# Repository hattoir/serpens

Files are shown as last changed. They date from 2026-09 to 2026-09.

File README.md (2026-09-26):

# Serpens EX-1 — 展示用ヘビ型ロボット 制御ソフトウェア

9軸（胴体ヨー×6 + 首ピッチ J7 + 頭ヨー J8 + 頭ロール J9）のヘビ型ロボットを、Python だけで動かすための
ソフトウェアです。**モックファースト**で作っており、実機が1台もなくてもシミュレータ上で全機能が動きます。

- ROS 2 不使用 / LLM 不使用（行動選択は手書きの効用関数）
- 寸法・しきい値・ゲインは全部 `config/robot.yaml`（コードにマジックナンバーを書かない）
- 実機接続は `--bus feetech --port COM5`。**ただし引数を足すだけで展示ができるわけではない**。
  実機は待機（停止）から始まり、**実観測の自己位置・床の校正・ESP32 駆動リンク**が揃うまで
  自律走行は開始できない（`serpens/safety.py`）。ESP32 ファームは Phase 2 で作る（未実装）

---

## 1. セットアップ（Windows 11 / Python 3.12）

PowerShell で、このフォルダ（`serpens/`）に移動してから実行します。

```powershell
py -3.12 -m venv .venv
.\.venv\Scripts\python.exe -m pip install --upgrade pip
.\.venv\Scripts\python.exe -m pip install -r requirements.txt
.\.venv\Scripts\python.exe -m pip install --no-deps -r requirements-nodeps.txt
.\.venv\Scripts\python.exe tools\check_env.py
.\.venv\Scripts\python.exe -m pytest
```

`Activate.ps1` で venv を有効化したい場合、PowerShell の実行ポリシーで止められることがあります。
その場合は上のように `.\.venv\Scripts\python.exe` を直接呼べば有効化は不要です。
VSCode ではコマンドパレット →「Python: Select Interpreter」→ `.venv` を選んでください。

### なぜ2段階インストールなのか（opencv の競合）

ArUco を使うので **`opencv-contrib-python` だけ**を入れます。ところが `ultralytics` は
`opencv-python` に依存しており、普通に `pip install ultralytics` すると両方が入って `cv2` が壊れます
（`cv2.aruco` が消える、import が不定になる等）。

そこで:
1. `requirements.txt` … ultralytics の依存を **opencv-python だけ除いて** 列挙
2. `requirements-nodeps.txt` … ultralytics 本体を `--no-deps` で入れる

`pip check` は「ultralytics requires opencv-python」と警告しますが、**想定どおりなので無視**してください。
万一 `opencv-python` が入ってしまったら:

```powershell
.\.venv\Scripts\python.exe -m pip uninstall -y opencv-python opencv-python-headless opencv-contrib-python
.\.venv\Scripts\python.exe -m pip install opencv-contrib-python
```

### サーボ SDK について

`ftservo-python-sdk`（Feetech 公式リポジトリ由来、import 名 `scservo_sdk`）を使います。
`WritePosEx()`（位置・速度・加速度の同時指定）、`read1ByteTxRx()` / `read2ByteTxRx()`、
Sync Read / Sync Write が揃っています。
よく似た名前の `feetech-servo-sdk` は機能削減版（`sms_sts` が無い）で、しかも同じ `scservo_sdk` という
名前でインストールされて上書きし合うので、**入れないでください**（`tools/check_env.py` が検出します）。
なお `scservo-sdk` という名前のパッケージは PyPI にありません。

### YOLO の重み（人物検出に必要。自動ダウンロードはしない）

**展示会場にネットは無い前提**です。ultralytics は重みのダウンロードや更新確認で勝手に外へ出るので、
`serpens/app.py` の先頭で次を設定してから import しています（import より前でないと効きません）。

```
YOLO_AUTOINSTALL=false   足りないパッケージを勝手に pip install しない
YOLO_OFFLINE=true        オンライン判定を常に false にする（重みの取得・更新確認をしない）
YOLO_HUB_OFFLINE=true    Ultralytics HUB へ通信しない
```

**置いてある重み**（取得済み。git には入れない）

| 項目 | 値 |
|---|---|
| ファイル | `models/yolo11n.pt`（場所は config の `person.model_path`） |
| 取得元 | https://github.com/ultralytics/assets/releases/download/v8.3.0/yolo11n.pt |
| サイズ | 5,613,764 バイト |
| SHA256 | `0ebbc80d4a7680d14987a577cd21342b65ecfd94632bd9a8da63ae6417644ee1` |
| 取得日 | 2026-09-12 |

置き直すときは上の URL から取得し、SHA256 が一致することを確認してください。

```powershell
.\.venv\Scripts\python.exe -c "import hashlib,pathlib;print(hashlib.sha256(pathlib.Path('models/yolo11n.pt').read_bytes()).hexdigest())"
```

**動作確認**（ultralytics 同梱の bus.jpg。4人写っています）

```powershell
.\.venv\Scripts\python.exe tools\perception_live.py --source .venv\Lib\site-packages\ultralytics\assets\bus.jpg --homography output\_test_h.json --frames 1 --no-window
# → [  0.00s] markers=[]  人=4
```

**オフライン起動の確認（展示前に必ず実行）**

ネットワークを遮断した状態で最後まで動くことを、次のツールで確認できます（外へ出ようとした瞬間にエラーになります）。

```powershell
.\.venv\Scripts\python.exe tools\offline_check.py --camera 0 --gui --seconds 12
# → [オフライン検証] 最後まで動きました
```

`pytest tests/test_offline.py` でも、遮断下で重みの読み込みと推論ができることを確認しています。

**注意**: YOLO の CPU 推論中は Python の GIL を握るため、制御周期が跳ねます（実測: 最悪 96ms、12秒で11回）。
`person.detect_hz`（既定 5Hz）と `person.imgsz`（既定 480）で調整できます。

---

## 2. Windows 固有の注意

### 2.1 COM ポート番号の確認

サーボ用（Waveshare Bus Servo Adapter (A)）と頭部用（XIAO ESP32S3）で **USB が2本**あり、
それぞれ別の COM 番号になります。どちらがどちらか、1本ずつ抜き差しして確認してください。

- **デバイスマネージャ**: スタートボタン右クリック → デバイスマネージャ →「ポート (COM と LPT)」
- **PowerShell**: `[System.IO.Ports.SerialPort]::GetPortNames()`
- **Python（pyserial）**: `.\.venv\Scripts\python.exe -m serial.tools.list_ports -v`

COM 番号は USB の挿し口を変えると変わることがあります。展示会場では**毎回同じ口に挿す**こと。
番号を固定したい場合はデバイスマネージャ → ポートのプロパティ → ポートの設定 → 詳細設定 →
「COM ポート番号」で変更できます。

### 2.2 Waveshare Bus Servo Adapter (A) の接続

- 基板に **USB Type-C** があり、ジャンパ2個で切り替えます:
  **位置A = UART制御 / 位置B = USB制御（PC直結）** → 本プロジェクトは **位置B**。
  別途 USB-TTL 変換器は不要で、これ1枚で PC から直結できます（LeRobot SO-100/SO-101 と同じ標準構成）。
- 半二重（TX/RX 1本線）の方向切替は基板上で処理されるので、**PC側でエコーバックを読み捨てる処理は不要**です。
- USB 側はネイティブの USB CDC と見込んでいます（LeRobot のポート例が `ttyACM0` / `usbmodem` のため）。
  Windows では「USB シリアル デバイス (COMx)」として**標準ドライバで認識され、CH340 等のドライバ導入は不要**の見込み。
  （`ttyACM` は「CDC-ACM クラス」という意味なので、CDC 対応の変換チップの可能性もあります。
  どちらでも Windows 標準ドライバで動く点は同じです。）→ **実機で要確認**

### 2.3 USB シリアルの latency timer（CH340系の USB-TTL を使う場合のみ）

**Bus Servo Adapter (A) はネイティブ CDC なので、この設定は不要の見込みです（実機で要確認）。**
代わりに CH340 / FTDI 系の USB-TTL 変換器でサーボをつなぐ場合だけ、以下を行ってください。

これらのドライバは既定で受信データを最大 16ms 溜めてから PC に渡します。サーボは
「送信 → 応答待ち」を繰り返すので、1往復ごとに最大 16ms 待たされ、9軸 × 50Hz で
キーフレームを送ると**動きがカクつきます**。

手順（FTDI の場合）:
1. デバイスマネージャ →「ポート (COM と LPT)」→ 該当 COM ポートを右クリック →「プロパティ」
2. 「ポートの設定」タブ →「詳細設定」
3. 「待ち時間 (msec)」（英語表示では *Latency Timer (msec)*）を **16 → 1** に変更 → OK
4. **USB を抜き差し**して反映（または PC 再起動）

どの構成でも、実際の往復時間は STEP 8 の `tools/servo_setup.py` で測って確認します。

### 2.4 電源と配線

```
 12V 電源 (5A以上, 推奨10A以上)
    │  DCジャック or ネジ端子
    ▼
 ┌──────────────────────┐  USB-C (ジャンパ=B)
 │ Bus Servo Adapter (A)│──────────────────── PC (COMx)
 └──────────┬───────────┘
            │ 3線 (GND / 12V / 信号) デイジーチェーン
   J1 ─ J2 ─ J3 ─ J4 ─ J5 ─ [★] ─ J6 ─ J7 ─ J8 ─ J9
                              ↑
            必要ならここで 12V を分岐注入（GND 共通）
```

- STS3215 は 1 個あたりロック電流 2.7A（Waveshare Wiki の仕様値）。9 個が同時に踏ん張ると
  電源側は数十 A になり得ます。**律速になるのは電源容量と、デイジーチェーンのコネクタ・細い線の電流容量**です。
- 末端（頭側）で電圧が落ちる場合は、バスの中間で 12V を**分岐注入**してください（GND は必ず共通）。
- 電圧は `read_state()` の電圧で監視できます。展示中の電圧低下はログに残す予定です（STEP 7）。

XIAO ESP32S3（頭部）は別の USB で PC に接続します（115200 bps、行指向 ASCII。仕様は STEP 2 の `head_io.py` 参照）。

### 2.5 その他
- ユーザー名に日本語が含まれていても動作は確認済み（venv / pip / pytest）。
- **`cv2.imread` / `cv2.imwrite` は日本語を含むパスを開けません**（Windows 版 OpenCV の制限）。
  画像の読み書きは `np.fromfile` + `cv2.imdecode` か PIL を使うこと（`perception/camera.py` の ImageSource 参照）。
- COM ポートは同時に1プロセスしか開けません。Arduino IDE や別のシリアルモニタを閉じてから起動すること。

---

## 3. 実行方法（STEP ごとに更新）

### 動作確認用ツール

```powershell
# STEP 2: モックサーボの追従・負荷・温度変化をコンソールに表示
.\.venv\Scripts\python.exe tools\demo_mock_servo.py --heat-tau 60
# STEP 3: 9軸の角度列と、姿勢（home / とぐろ / 鎌首）の形を図にする → output/step3_motion.png
.\.venv\Scripts\python.exe tools\plot_motion.py
# STEP 4: シミュレータを上から見た図（+GIF）と、歩容ごとの「1周期あたりの前進量」
.\.venv\Scripts\python.exe tools\sim_view.py --gif
# STEP 5: 仮想カメラで知覚を試す（本物の ArUco 検出、人は仮想の検出器）→ GIF と時系列グラフ
.\.venv\Scripts\python.exe tools\perception_demo.py
# STEP 5: 実写（印刷したマーカ）。先に四隅をクリックして床の校正
.\.venv\Scripts\python.exe tools\make_aruco.py            # → output/aruco_markers_A4.png を実寸で印刷
.\.venv\Scripts\python.exe tools\calibrate_floor.py --source 0
.\.venv\Scripts\python.exe tools\perception_live.py --source 0
# STEP 6: 人の座標を動かして一連の振る舞いを見る → output/step6_behavior.gif と内部状態の時系列
.\.venv\Scripts\python.exe tools\behavior_demo.py
```

### 行動の設計（STEP 6）

毎制御周期（50Hz）の流れ（`behavior/brain.py`）:

```
知覚（ヘビの位置姿勢・追跡中の1人・タッチ・サーボ最高温度）
 → 刺激（presence / proximity / approach / touch / novelty / looking / alone）
 → 内部状態（Curiosity / Affection / Stress / Attention = 一次遅れ、Energy = サーボ温度から）
 → 効用（9状態、±8% の乱数）→ 状態機械（ヒステリシス 1.15 倍・最小継続 4 秒）
 → 状態ごとの動作（移動 controller.py / しぐさ expression.py）→ アニメーター → サーボ
```

- `internal_state.py` … dx/dt = −(x−x0)/τ + Σ gain×刺激。係数は `behavior.internal`。
  Energy は最高温度 `temp_fresh_c`（=1）〜`temp_tired_c`（=0）の直線。熱い = 疲れている
- `utility.py` … 手書きの効用（式は docstring）。係数は `behavior.utility.weights`。
  GUI の「いま何を考えているか」は `thought_line()`（例: `Curiosity 0.82 > Rest 0.31 → 接近`）
- `fsm.py` … 最小継続時間（状態ごとに上書き可: PETTED 2s / ALERT 2s / COIL_REST 20s / SLEEP 8s）、
  割り込みは PETTED だけ。ALERT は「新しい人に気づいた瞬間」に直接切り替える
- `controller.py` … 目標点 → γ0（向きの誤差 × ゲイン）と周波数（速さ ÷ 1周期の前進量）。
  周期は遅くするときだけ延ばす（速くするために短くしない）。1m 以内 8cm/s（**気づく前でも必ず**）、
  頭先端から 400mm で停止（歩容が止まるまでの惰性ぶん早めに止める）。
  マット端では後退しながら中央へ向き直る。マットの外の人へ近づくときは、人の方を向いて端に着いたら止まる
- `expression.py` … 生き物らしさ a〜j（数値はすべて `behavior.expression`）
- `sim/session.py` … 実機なしで全部をつないだもの（GUI の `--sim` もこれを使う予定）
- 目の色・明るさは状態ごと（`behavior.eyes`）。ESP32 のフェイルセーフ（3 秒）より短い間隔で送り直す

### 知覚の設計（STEP 5）

- `perception/homography.py` … マット四隅4点 → 画像↔床の射影変換（JSON 保存）。胴体上面のマーカ（高さ 50mm）は
  `camera.position_mm` を与えると視差補正する（高さ 1.5m・水平 1m で約 33mm のずれ）。広角レンズの歪みは取れない
- `perception/aruco_locator.py` … DICT_4X4_50 の ID0（尾）/ ID1（首）。小さいマーカ向けに検出パラメータを調整済み
  （`aruco.detector_params`）。2枚の距離が `aruco.max_marker_gap_mm` を超えたら誤検出として尾を捨てる
- `perception/snake_pose.py` … θ_body は1周期の移動平均（`snake_pose.heading_filter`）。一次ローパスは
  定常旋回で ω·τ（約 40°）遅れるため。移動平均の遅れは τ/2
- `perception/person_detector.py` … YOLO（CPU、person のみ）→ bbox 下辺中央を足元として床座標へ。
  追跡は「ヘビの首に最も近い1人」だけ、切替は 2 秒ヒステリシス、0人でも 3 秒保持、マット中心から 1.5m の外は無視
- `sim/virtual_camera.py` … カメラ無しでも知覚を通しで試せる仮想カメラ（マーカは本物の画像を貼って描く）
- **マーカの大きさ**: 40mm は 1280×720 だとマット奥で 11〜20px しかなく、仮想カメラでも検出率 93〜98%。
  1920×1080 なら 100%。**カメラは 1080p で使う**（`camera.width_px`）
- **カメラとマットの間に人が立つと、マーカが隠れる**（仮想カメラで確認）。カメラの置き場所に注意

### シミュレータの設計（STEP 4）

- `sim/world.py` … 車輪のあるリンク（`sim.wheel_links` = 尾端〜J7 の7リンク × 2輪 = 14輪）は横滑りしない、
  という拘束を全リンク分まとめて最小二乗で解き、胴体全体の剛体速度 (vx, vy, ω) を毎ステップ求める。物理エンジンなし。
  - 車輪の進行方向には転がり抵抗の重み `belly.profiles[type][profile].tangential`（推定値 0.02。**要実機校正**）。腹側は Wheel / Snake を切り替えられる
  - J7 より先は車輪なし。頭部が床にあるときは PTFE / フェルトのパッド（`sim.pad_links`、等方の軽い摩擦）
  - 床から浮いたリンク（鎌首の頭側）は拘束に入れない。マットからはみ出したら全体を内側へ押し戻す
- ヘビの位置姿勢（`perception/snake_pose.py`。ArUco でもシミュレータでも同じ処理）
  - 位置 = 首マーカ。**首マーカは J7 より胴体側（J6-J7 リンク上）に貼る**（J7 より先だと鎌首で傾いて見えない）。
    尾マーカは尾端-J1 リンク上。どちらも上面
  - θ_body = 尾マーカ → 首マーカ。蛇行で振れるので、時定数 = 歩容1周期のローパス後の値を移動制御に使う（生値も保持）
  - θ_head = θ_body + J8（「人を見ているか」の判定用）
- **1周期あたりの前進量（シミュレータ, 転がり抵抗 0.02）**: forward 約 384mm。
  実機では 200〜300mm/周期（周期2秒で 10〜15cm/s）と予想。**速度のために周期を短くしない**（静粛性優先）。
- 旋回は γ（オフセット）だけ。`gait.turn_profile: head_weighted`（γ(n) = γ0·n/N）が既定で、
  γ0 = ±20° で半径 約480mm。γ0 は1周期かけてランプする。
  - uniform と head_weighted を同じ旋回率で比べると半径は同じで、尾が頭の軌跡をなぞる精度が head_weighted の方が上
    （ずれ平均 91mm vs 115mm）。
- とぐろは**尾から順に巻き、頭を最後に引き込む**（`poses.coil_sequence`）。全関節同時より滑走が少ない。

### モーション層の設計（STEP 3）

- 関節角の符号: yaw + = 上から見て左、pitch + = 頭が上がる、roll + = 右に傾く（`motion/kinematics.py`）
- `motion/gait.py` … α(n,t) = A·sin(Ω·n + ω·t) + γ(n)。n=0 が J1（尾側）。ω>0 で前進、ω<0 で後退。
  旋回入力は γ だけ（振幅勾配は平面の蛇行では旋回しないことを確認して削除）。
- `motion/poses.py` … home（J7 = +8°：頭をわずかに浮かせる）/ rest（緩い弧）/ rear_up（土台 arc）/
  stretch（伸び。人がいないときだけ）/ head_look / relax。旧 coil・s_curve は `legacy_poses`。
  head_look で J7 を指定すると「人を見る」範囲（`neck.look_min_deg`〜`look_max_deg`）に制限される。
- `motion/animator.py` … 出力 = キーフレーム + 歩容（加算）+ 呼吸（加算）。
  キーフレームがその軸の `max_speed_dps`（胴体 240 / J7 120 / J8・J9 90 °/s）を超える速さを要求したら、
  自動で時間を延ばす。`order` と `stagger_s` で関節ごとに時間差をつけられる（とぐろを尾から順に）。
  `freeze()` で呼吸も含めて全停止し、`unfreeze()` で続きから再開する。

### ハードウェア層の設計（STEP 2）

- `serpens/hw/servo_bus.py` … 抽象クラス `ServoBus`。角度は**関節角 [deg]**（0° = まっすぐ）。
  ソフトリミット（config の `min_deg` / `max_deg`）でのクランプはここで共通に行う。
  可動域は3段（`geometry_*` ⊇ `mechanical_*` ⊇ `min_deg`/`max_deg`）で、包含関係を `load_config` が検査する。
  胴体ヨーは CAD `Serpens_BELLY_R03_TWO_LINK_REVIEW` の ±64°（干渉なし）に対し operational ±60°（暫定）。
- `serpens/hw/mock_bus.py` … 一次遅れ追従。温度は一次系で、時定数 `mock_servo.heat_tau_s` を変えられる。
- `serpens/hw/feetech_bus.py` … 実機用。根拠は [docs/sts3215_registers.md](docs/sts3215_registers.md)。
  取り付け向き（`direction`）とホーン取付角オフセット（`horn_offset_deg`）は config で関節ごとに設定する。
- `serpens/hw/state_poller.py` … 位置と熱系（負荷・電圧・温度）を別頻度で読む。SYNC READ 非対応なら位置の頻度を落とす。
- `serpens/hw/head_io.py` … 頭部 XIAO ESP32S3。`SerialHeadIO`（自動再接続）と `MockHeadIO`（同じ行形式を生成）。
- 切り替えは `make_bus("mock" | "feetech", cfg, port)`。

### アプリ（STEP 7）

```powershell
# シミュレータのみ（実機なし）。GUI が開く
.\.venv\Scripts\python.exe -m serpens.app --sim
# 人の出入りを自動で再現（展示のリハーサル）
.\.venv\Scripts\python.exe -m serpens.app --sim --demo
# Webカメラで人検出 + シミュレータのヘビ
.\.venv\Scripts\python.exe -m serpens.app --sim --camera 0
# 実機（実機テストは未実施）
.\.venv\Scripts\python.exe -m serpens.app --bus feetech --port COM5
# GUI 無しで動作だけ確認 / GUI を GIF に記録
.\.venv\Scripts\python.exe -m serpens.app --sim --no-gui --seconds 10
.\.venv\Scripts\python.exe -m serpens.app --sim --demo --seconds 40 --record output\step7_gui.gif
```

キーボード

| キー | 意味 |
|---|---|
| **G** | 開始（待機 → 走行）。実機は開始条件を満たさないと動かない |
| **S** | **通常停止**。歩容を即時に止め、現在姿勢を保持（出力へ保持指令を送り続ける） |
| **E** | **緊急停止**（ラッチ）。通常操作・予約済みの演出では解除されない |
| **U** | 緊急停止の解除 → **待機**（走行は再開しない。再開は G） |
| **L** | 駆動無効化（脱力）。**停止中の明示操作のみ**。実機未検証 |
| **P** | シミュレーションの一時停止（実機では使わない） |
| **R** / **H** | ホーム復帰 / ホーム姿勢（**走行中のみ**。停止中は動かさない） |
| **D** / **C** / **T** / **Q** | デモの人 / 校正案内 / タッチ（モック） / 終了 |

### 停止の3種類（`serpens/safety.py`）

| 状態 | 意味 | 出力 | 解除 |
|---|---|---|---|
| RUN | 走行 | 行動が決めた指令 | — |
| HOLD | 通常停止 | 歩容を即時停止し、現在姿勢の保持指令を送り続ける（トルクは入れたまま） | G |
| DISABLED | 駆動無効化 | トルク OFF（脱力）。明示操作のみ。**実機未検証** | G |
| EMERGENCY | 緊急停止 | HOLD と同じ（config で DISABLED も選べる。**実機未検証**） | U → 待機 |

- **停止で勝手にホーム姿勢へ動かさない／全軸を無条件に脱力しない。** 停止中に動くのが最も危険
- 停止中も**監視は続ける**（温度・電圧・負荷を読み続ける）
- 停止時に**予約済みの演出（反応・見る・かしげる）を破棄**する。解除後に勝手に動き出さない
- 終了時は「停止を出力へ送る → スレッド join → 切断」を必ず通り、失敗はコンソールと GUI に出す。
  終了時にトルクを切るかは `behavior.safety.stop.disable_torque_on_exit`（既定 false = 保持したまま切断。**実機未検証**）

### ⚠ PC 側だけでは機体の安全は完成しない

`S` / `E` は **PC が生きている間だけ**有効。**PC の強制終了・USB 断・アプリのクラッシュでは、
サーボは最後に受けた目標角を保持し続ける**（Feetech サーボは自分で止まらない）。

**機体側の watchdog（heartbeat 途絶で ESP32 が単独で停止）が Phase 2 の必須項目。**
現状の `head_io` のフェイルセーフは目の表示を戻すだけで、駆動には効かない。

### 駆動リンク（Phase 2。PC ⇄ ESP32-S3）

仕様は [`docs/link_protocol.md`](docs/link_protocol.md)、確認結果は
[`docs/phase2_acceptance.md`](docs/phase2_acceptance.md)。

- PC が送るのは**歩容のパラメータ（10 バイトの `DRIVE`）だけ**。9軸の角度は ESP32 が作る
- **止まり方は二段構え。** `DRIVE` は期限（TTL 300ms）付きで、切れれば保持。
  `heartbeat` が 400ms 途絶すれば待機まで落ちる。**PC が死んでも USB が抜けても機体が自分で止まる**
- 緊急停止は**機体側でラッチ**。再接続でも `ARM` でも解除されず、`CLEAR_FAULT` は待機へ戻すだけ
- 上限（振幅・周波数・旋回・頭部角・速度）は**機体が持つ**。PC の設定では緩められない

```powershell
# 行動・GUI を駆動リンク経由で動かす（模擬 ESP32。実機は不要）
.\.venv\Scripts\python.exe -m serpens.app --sim --robot link
# 実 ESP32 につなぐ（**実機未検証**）
.\.venv\Scripts\python.exe -m serpens.app --robot link --link-port COM7
# 完了条件 1〜12 の確認 + 時間の実測（模擬機体。実機は不要）
.\.venv\Scripts\python.exe tools\link_check.py
# 歩容パラメータの掃引（速さ・旋回性・蛇らしさ・滑らかさ・負荷・電力目安）
.\.venv\Scripts\python.exe tools\gait_sweep.py
# 制御周期 50Hz が知覚スレッド（描画 / ArUco+YOLO）と同時でも守れるか（このPCの測定）
.\.venv\Scripts\python.exe tools\loop_timing.py
# 6/8/10 軸の比較表（波数掃引・速度合わせ。KINEMATIC_SIM）→ output\body_compare.md
.\.venv\Scripts\python.exe tools\body_compare.py
# Human Perception Pilot: 匿名クリップ → 提示順 → 集計（docs/human_pilot.md）
.\.venv\Scripts\python.exe tools\pilot_clips.py --seed 1
.\.venv\Scripts\python.exe tools\pilot_order.py --participants 10 --seed 42
.\.venv\Scripts\python.exe tools\pilot_analysis.py output\pilot\responses.csv --key output\pilot\clip_key.json
# Floor Watch: Home AI との Task / Event API（docs/task_event_api.md、schemas/*.json）は pytest で検証（ハード不要）
# Floor Watch の自己位置を模擬で評価（タグを見失ってからの誤差と σ。KINEMATIC_SIM 相当、実機ではない）
.\.venv\Scripts\python.exe tools\localization_sim.py --seeds 5 --seconds 300
# Floor Watch の画像処理を合成データで 2 段（patrol / inspect）評価（SIMULATED。実写は data/floorwatch/<set> を --root で）
# 本物の MQTT（retain / LWT / QoS1）: pip install paho-mqtt（開発用の任意依存）+ mosquitto 実行ファイルがあれば tests/test_mqtt_live.py が一時ポートで起動して検証
.\.venv\Scripts\python.exe tools\floorwatch_eval.py --synthetic
# 動きの質（静止率・一次反応・GAR・可視波数・LDJ。KINEMATIC_SIM。回帰指標であって人の評価の代替ではない）
.\.venv\Scripts\python.exe tools\motion_quality.py
# 模擬 Vision の閉ループを故障ごとに試す（Phase 4。実カメラの値ではない）
.\.venv\Scripts\python.exe tools\vision_check.py
# ファームのコンパイル（**書き込みはしない**）
.\.venv\Scripts\python.exe tools\build_firmware.py
# ファームと突き合わせる参照角度列 → data/gait_reference.csv
.\.venv\Scripts\python.exe tools\make_gait_reference.py
```

| 場所 | 中身 |
|---|---|
| `serpens/link/snake.py` | **`SimulatedSnake` / `RealSnake`**。上位から見た2つのヘビ（同じ Interface） |
| `serpens/link/protocol.py` `messages.py` | フレームと payload（通信路を持たない） |
| `serpens/link/device.py` `device_motion.py` `device_servos.py` | **Virtual ESP32**（7状態）と仮想サーボバス |
| `serpens/link/client.py` | PC 側。heartbeat・TTL・停止理由の履歴・NaN/Inf の遮断 |
| `serpens/link/transport.py` `faults.py` `harness.py` | 偽経路と**故障注入**（loss / delay / 順序入れ替え / 重複 / CRC 破損 / 抜去 / 再起動） |
| `firmware/serpens_esp32/` | Arduino スケッチ。**未コンパイル・未書き込み**、配線が未確定 |

機体の状態は7つ（`BOOT / DISARMED / ARMED_HOLD / DRIVING / FAULT_HOLD /
EMERGENCY_LATCHED / TORQUE_DISABLED`）。テレメトリは**指令角ではなく実測角**を返し、
`source`（SIMULATION / HARDWARE）で模擬か実測かが分かる。
GUI 下段の関節ペインに、9軸の指令角・実測角・安全状態・機体状態が出る。

**「確認済み」と書くときは4段のどれかを指す**（`docs/verification_status.md`）:
`SIMULATED` / `SOFTWARE_VERIFIED` / `HARDWARE_UNVERIFIED` / `HARDWARE_VERIFIED`。
現在 `HARDWARE_VERIFIED` は **0 件**。

`--robot link` のとき、PC が送るのは**歩容のパラメータ（DRIVE）・胴体の姿勢（BODY）・
首と頭の角度（HEAD）**だけで、9軸の角度列は送らない。胴体の波は機体が作る。
そのため**アプリを強制終了しても、USB を抜いても、機体が自分で止まる**
（`tests/test_phase3_link_robot.py` で確認）。`--robot direct`（既定）は従来どおり角度を直接書くので、
**PC が死ぬとサーボは最後の指令角を保持し続ける**。

### 実機経路の接続（Phase 1 で直した部分）

```powershell
# サーボのみ（頭部 I/O 未接続 → ToF・タッチ・目は使えない。モックを実センサーとして使わない）
.\.venv\Scripts\python.exe -m serpens.app --bus feetech --port COM5
# 頭部も繋ぐ
.\.venv\Scripts\python.exe -m serpens.app --bus feetech --port COM5 --head-port COM6
```

- サーボバスと頭部 I/O は**セッションより先に作って注入**する。これで
  状態監視（`ServoStatePoller`）・位置指令（`Animator.send`）・トルク操作（`Expression`）が
  **同じ接続先**を参照する（以前は `session.bus` だけを差し替えていて、監視と脱力がモックに残っていた）
- **実機のロボット位置はまだ実観測ではない**（`world` の運動モデル由来）。
  そのため実機の自律走行は禁止したままで、開始条件として画面とコンソールに理由を出す。
  ArUco → World State の結線は Phase 4
- テレメトリは軸ごとに最終取得時刻を持ち、`behavior.safety.telemetry.stale_after_s` より古い軸は
  GUI で「—」になる。値の出どころ（MockServoBus / FeetechServoBus）も表示する

### 3D 物理シミュレーション（任意 / MuJoCo）

`serpens/` 本体は MuJoCo に依存しない。**入っていなくても全機能が動く**（モックファースト）。

```powershell
.\.venv\Scripts\python.exe -m pip install -r requirements-sim3d.txt
.\.venv\Scripts\python.exe tools\gait_sweep_mujoco.py           # 歩容の掃引（Pareto 候補つき）
```

| 場所 | 中身 |
|---|---|
| `simulation/mujoco/model.py` | `config/robot.yaml` から MJCF を生成（手書きしない） |
| `simulation/mujoco/belly.py` | WHEEL / SNAKE_ISOTROPIC / SNAKE_ANISOTROPIC（異方性摩擦） |
| `simulation/mujoco/runner.py` | 走らせて測る（前進・トルク・エネルギー・追従誤差・飽和率） |
| `simulation/record.py` | run の記録（source / config hash / model digest / seed） |
| `simulation/bridge.py` `virtual_person.py` | World State への橋渡しと仮想の来場者 |

**結果には必ず `source` が付く**（`KINEMATIC_SIM` / `MUJOCO_SIM` / `HARDWARE`）。
簡易シミュレータと MuJoCo の数値を混ぜない。どちらも**現実ではない**。

### World State（Phase 4 の入口）

`serpens/world_state.py` の姿勢は**出どころ**を持つ:
`GROUND_TRUTH_SIM` / `ARUCO` / `PERSON_DETECTOR` / `DEAD_RECKONING` / `UNKNOWN`。
シミュレーションの真値を「Vision が成功した」として数えないため。
カメラを繋いだら、同じ World State の中身が差し替わるだけで行動側は変わらない。

### GUI の設計（STEP 7）

- 4分割。左上 カメラ映像（`--sim` では仮想カメラ）、右上 俯瞰マップ、左下 内部状態、右下「いま何を考えているか」
- 文字は大きく（状態名 26pt / 本文 20pt）、細いグレー文字は使わない（`gui/style.py`）
- 右下の1行は効用の数値をそのまま出さず、日本語の文にする（`gui/wording.py`）
  - 例: 「好奇心 0.78 が 注意 0.38 を上回ったので、近づくことにした（人まで約 886mm、400mm 手前で止まる）」
  - 例: 「撫でられている。力を抜いて、じっとしている」「サーボが58℃。冷えるまで休む」
- **制御と描画を分ける**: 制御は専用スレッドで 50Hz（`serpens/runner.py`）、GUI は 10fps で最新値を読むだけ。
  Windows ではタイマ分解能を 1ms にし、制御スレッドの優先度を上げている
- **制御周期の実測**（30秒、この PC）

  | 条件 | 平均 | 最悪 | 20%以上の遅延 |
  |---|---|---|---|
  | GUI なし | 19.99ms | 20.78ms | 0 / 1505 |
  | GUI あり | 19.99ms | 58.1ms | 5 / 1512（0.3%） |
  | GUI あり + GIF 記録 | 20.01ms | 64.7ms | 135 / 2999（4.5%） |

  GUI ありで時々跳ねるのは Python の GIL（描画中は制御スレッドが待たされる）。
  サーボへは「目標角」を送るので、数周期の遅れは動きの途切れにはならない。GIF 記録は開発用で、展示では使わない。

---

## 4. 実機が届いたら最初にやること

1. **`tools/servo_setup.py` を回す**（実機が届いた日に最初に使うツール。モックでも練習できます）

   ```powershell
   .\.venv\Scripts\python.exe tools\servo_setup.py                      # モックで練習
   .\.venv\Scripts\python.exe tools\servo_setup.py --bus feetech --port COM5
   ```

   | メニュー | 内容 |
   |---|---|
   | 1 | ポートの一覧と自動検出（サーボ用と頭部用の2本を見分ける） |
   | 2 | サーボのスキャン（ID 範囲を指定。見つからないときの確認手順も表示） |
   | 3 | **入力電圧の設定（最優先）**。EEPROM の最高/最低入力電圧を読み、電源電圧より低ければ警告して書き換える |
   | 4 | ID の一括設定（1個ずつ繋いで 1→9 を順に振る） |
   | 5 | 温度・電圧・負荷のライブ表示（1Hz、Ctrl+C で戻る） |
   | 6 | 現在負荷の符号ビットの検証（仮説 bit10 を実機で確かめる） |
   | 7 | SYNC READ の対応判定（非対応なら個別 READ に落ちることを確認） |
   | 8 | 中立位置（2047）で保持してホーンを取り付ける |

   EEPROM への書き込みは「トルク OFF → ロック解除（55番地に 0）→ 書く → ロック（1）」の順に行います。
   トルク OFF が必須かどうかは資料に記載が無いので、安全側に倒して必ず切っています（実機で要確認）。

2. **Sim-to-Real 校正**: 平らな床で直進歩容（forward / slow）を N 周期歩かせ、首マーカの移動距離を測る。
   `data/real_runs.csv` に1行ずつ足して（床材ごとに）、次を回す:
   ```powershell
   .\.venv\Scripts\python.exe tools\fit_sim.py
   ```
   シミュレータの belly プロファイルの `tangential` を 0〜0.2 でスイープし、実測に最も合う値を出す（図: `output/fit_sim.png`）。
   その値を config に書けば、以後シミュレータの移動量が実機に合う。**サンプルのダミー行は消すこと。**
   - 例: 300mm/周期なら ratio ≈ 0.054。予想の 200〜300mm/周期は ratio 0.05〜0.10 に当たる
   - 最適値がスイープ範囲の端に張り付いたら、モデルが実機を説明できていない（車輪の滑り方が違う等）。相談すること

## 5. トラブルシュート

### サーボが PING に応答するのに、まったく動かない

**まず最高入力電圧（EEPROM 14番地）を疑ってください。** Waveshare のメモリテーブル（7.4V 版の表）では
初期値が **80 = 8.0V** です。12V 版のサーボでも同じ値のままだと、12V を入れた時点で過電圧になり、
一切動かない可能性があります（「実機を繋いだ初日に全部動かず数時間溶かす」タイプの罠）。

1. `tools/servo_setup.py`（STEP 8）で 13〜16 番地（最高温度・最高/最低入力電圧・最大トルク）と
   65 番地（サーボ状態。bit0 = 電圧エラー）を読む
2. 最高入力電圧が電源電圧より低ければ書き換える（EEPROM のロック解除 → 書き込み → ロック）
3. EEPROM 書き込み時にトルク OFF が必要な機種があるので、ツールは書き込み前にトルクを切る

### その他の実機確認事項（届いたら）
- 現在負荷の符号: 「下位10bit = 大きさ、bit10 = 方向」は**仮説**（`servo.load_sign_bit: 10`）。手で押して符号を確認する
- SYNC READ に応答するか（しなければ自動で個別 READ に切り替わり、位置の読み出しは 10Hz に落ちる）
- **TODO: 外皮ニットを着せたら可動範囲を再測定し、`joints[].mech_*` / `min_deg` / `max_deg` を更新する**
- サーボホーンの取付角を測り、`joints[].horn_offset_deg` に入れる

---

## 6. ディレクトリ構成

```
serpens/
  README.md  requirements.txt  requirements-nodeps.txt  pytest.ini
  config/robot.yaml          全パラメータ（寸法・しきい値・ゲイン）
  serpens/
    hw/          servo_bus.py(抽象) feetech_bus.py mock_bus.py head_io.py
    motion/      gait.py poses.py animator.py
    perception/  camera.py aruco_locator.py person_detector.py homography.py
    behavior/    internal_state.py fsm.py utility.py controller.py
    sim/         world.py
    gui/         app.py
    app.py  keys.py
  tools/         check_env.py make_aruco.py calibrate_floor.py servo_setup.py
  tests/
```

---

## 7. 進捗

| STEP | 内容 | 状態 |
|---|---|---|
| 1 | 環境構築 | ✅ |
| 2 | サーボ抽象層とモック / 頭部 I/O | ✅（実機テストは未実施） |
| 3 | 歩容エンジン・姿勢・アニメーター | ✅ |
| 4 | 2D シミュレータ | ✅ |
| 4.5 | Sim-to-Real 校正の器（fit_sim.py） | ✅ |
| 5 | 知覚（ArUco・ホモグラフィ・人の追跡） | ✅（YOLO は重みを置いてから確認） |
| 6 | 内部状態と行動 | ✅ |
| 7 | 展示用 GUI | ✅ |
| 8 | 実機用ツール（servo_setup.py） | ✅（モックで全メニュー確認。実機テストは未実施） |

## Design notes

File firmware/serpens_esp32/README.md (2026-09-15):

# Serpens EX-1 駆動リンク ファームウェア（雛形）

PC が死んでも機体だけでヘビを止めるための基板側。仕様は [`docs/link_protocol.md`](../../docs/link_protocol.md) v1。

## 状態: **コンパイル可・未書き込み・実機未検証**

2026-09-16: `arduino-cli` で**コンパイルが通ることを確認**（`SOFTWARE_VERIFIED`）。

```bash
.venv/Scripts/python.exe tools/build_firmware.py
```

結果（esp32 core 2.0.17 / FQBN `esp32:esp32:XIAO_ESP32S3`）:
フラッシュ **255,809 バイト（7%）** / RAM **18,632 バイト（5%）**。

**書き込みは一度もしていない。** 実機（ESP32-S3 と STS3215）が手元に無いため、
振る舞いの正しさは Python の参照実装（`serpens/link/device.py`）で検証してある
（`tests/test_phase2_device.py` / `tests/test_phase2_safety.py`、48 件）。
このスケッチは**その参照実装を同じ判断順で C++ に写したもの**で、実機が来たら
`tools/link_check.py` の手順で条件 1〜15 を測り直す。

| ファイル | 中身 |
|---|---|
| `link.h` | フレーム・CRC・enum（`serpens/link/protocol.py` の写し） |
| `config.h` | 時定数・上限・関節（`config/robot.yaml` の写し） |
| `serpens_esp32.ino` | 状態機械（7状態）・watchdog・歩容生成・テレメトリ v2 |

コンパイル時にも大きさを検査している（`link.h` の `static_assert`）:
テレメトリ 9軸 = 26 + 9×11 = **125 バイト ≤ MAX_PAYLOAD 192**。

**三つ（robot.yaml / protocol.py / この二つのヘッダ）は同じ値を持つ。片方だけ直さないこと。**

## 決まっていないこと（勝手に決めない）

1. **駆動リンク用の基板**を、頭部センサ用の XIAO ESP32S3 と兼用にするか、別基板にするか。
   兼用なら頭部の ASCII 行プロトコル（`serpens/hw/head_io.py`）と同じ USB に同居することになる。
2. **サーボの半二重 TTL をどう作るか。** Waveshare Bus Servo Adapter (A) を挟むのか、
   方向制御ピン付きのトランシーバを基板に載せるのか。`config.h` の `SERVO_*_PIN` は `-1`（未定）。
3. 電源の取り方（12V → 基板の 5V/3.3V）。

これが決まるまで **書き込まないこと**。`writeServos()` と温度・fault の読み出しは空のままにしてある。

## 未実装（TODO）

- `writeServos()`: 9軸の同期書き込み（`docs/sts3215_registers.md` の 41〜47 ブロック）
- サーボの状態読み出し（56〜63 ブロック）→ テレメトリの位置・負荷・温度・電圧・fault
- 過熱・過電流の実測値による緊急停止（いまは読み値が 0 なので発火しない）
- 起動時に現在角を読んでから `gGoal` に入れる（いまはホーム姿勢を仮定している。
  **実機でここを直さないと、電源投入時に現在角からホームへ飛ぶ危険がある**）
- とぐろ（`POSE` の id 1 以降）。いまは home のみ

## ビルド（実機が来たら）

- ボード: XIAO ESP32S3 または ESP32-S3 DevKit
- USB CDC On Boot: **Enabled**（`Serial` がネイティブ USB になる）
- ライブラリ: サーボは `SCServo` 系または `ftservo` 系（PC 側の `ftservo-python-sdk` と同じ系統）

## 実機で最初に確かめること（順番）

1. `PING` に ACK が返る。`TELEMETRY` が 10Hz で届く（`tools/link_check.py --port COMx`）
2. **サーボを繋がない状態**で、`ARM` → `DRIVE` → `boot_id`・`stop_reason` が仕様どおり動く
3. USB を抜く → 出力が止まる（サーボ未接続でも、テレメトリの `flags` から分かる）
4. サーボ1個だけ繋いで、ホーム姿勢の保持と `STOP(mode=disable)` の脱力を確認
5. 9軸を繋いで `data/gait_reference.csv` と出力を突き合わせる（条件 1）
6. 条件 13/14/15 の実測を `docs/phase2_acceptance.md` に記録する

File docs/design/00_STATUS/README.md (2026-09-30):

# 00_STATUS — Design の今の進捗と、やってほしいこと（2026-09-30 時点）

| ファイル | 中身 |
|---|---|
| `PROGRESS.md` | 進捗（できたこと・数字・残り） |
| `USER_TODO.md` | **User にやってほしいこと**（印刷・確認・判断）。上から順 |
| `ENGINEERING_ASKS.md` | Engineering への依頼・回答待ち |
| `FILE_MAP.md` | 成果物の場所（STL・レポート・Fusion・ツール） |

> **先頭の注意（毎回書く）**: KNUCKLE DRUM を入れても、まっすぐ（124 mm³）に比べ、曲げた姿勢では 2250〜2939 mm³ が残る（**約 20 倍、18〜24 倍**）。背板の層（z ≥ 77）約 1020 mm³/姿勢は**未解決**、J1 ピッチは Engineering の動作範囲の回答待ち。**外形 STL だけのスクリーニングで、規格適合の確認ではない。SAFETY_UNVERIFIED。**

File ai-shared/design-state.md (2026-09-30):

# Design State

Design Agent が現在の設計状態を書く（Engineering Agent は書き換えない）。

Last updated: 2026-09-29（Run DESIGN-2026-09-29-01、User Decision USER-DEC-SERPENS-DESIGN-0001 を反映）
Updated by: Design Agent（Claude Code）
Git branch: `agent/design-floor-watch`（commit は別 worktree で行う。共有の作業ツリーの HEAD は動かさない。ENTRY-0004）

**HUMAN_EVALUATED = 0 / HARDWARE_UNVERIFIED。数値は DESIGN_ESTIMATE。Design の提案であって正式 Decision ではない。**
詳細: `../docs/design/concepts_2026-09-29.md`、数値: `../docs/design/results/concept_metrics_2026-09-29.json`

## User Decisions（2026-09-29、USER-DEC-SERPENS-DESIGN-0001。Design Run の成果に対する User の判断）

| # | 決定 | Design への効き方 |
|---|---|---|
| 1 | **CSAR を採用**。危険物を見つけてもその場で見せびらかさない / 再確認と位置登録の後、基本は危険物から少し離れる / 子どもが近い時は危険物ではなく子ども側を見る / **危険物のそばでとぐろは MVP で不採用** / 将来、遮蔽効果と誘導リスクを実験して再評価 | OPEN-SERPENS-DESIGN-004 = 採用（A）、005 = 離れる（A）。「遮蔽としてのとぐろ」は将来の実験候補に移す（MVP の行動には入れない） |
| 2 | **6 本目は暫定で Head Yaw** として Design を進めてよい。**最終決定ではない**。H0 摩擦試験で純粋な蛇行で十分動けるなら Head Yaw、移動性能が足りなければ Body Yaw を再検討 | 頭 yaw を首に置く意匠を進める。Body Yaw（全長 668 mm）に戻っても成り立つよう、頭・首の意匠を胴の節数に依存させない |
| 3 | **SD-01（Bean Head ＋ 同心ナックル）は継続検討してよい**。ただし **4 mm 一定のすき間は安全確定ではない**（Engineering 検証待ち）。**CAD_CONCEPT / KINEMATIC_SIM として扱う** | 挟み込みの数値は「2D の形の計算（KINEMATIC_SIM）」とだけ書く。安全・合格の語を使わない |
| 4 | **Agent ごとに Git worktree を分ける方針を正式採用**。Design Agent は Design worktree 以外の branch を切り替えない。shared / main の worktree の rebase や conflict には触れない | Design の commit は Design worktree（`agent/design-floor-watch`）だけ。共有ツリーの `ai-shared/` は追記のみ |
| 5 | `agent/design-floor-watch` は、**Design worktree が clean で rebase 中でないことを確認してから push してよい**。main への merge は禁止 | push 前に `git status` と rebase 状態を確認する |
| 6 | Fusion の SD-01 は、Fusion が復帰しても**既存ファイルを上書きせず、Recovery copy として別名保存**。最後の正常保存版を保持 | 復帰したら、まず状態を読み取り → 別名保存（例 `..._RECOVERY_20260929`）→ 元ファイルは触らない |
| 7 | **背板の修正は Recovery の後に続ける**。未保存の状態が分からないまま破壊的な編集をしない | 背板の作り直しは Recovery copy 上で、状態を読んでから |
| 8 | **ENTRY-0011（電装配置と同心ナックルの衝突）は Engineering の回答待ち**。Design だけで解決を確定しない | 段付きナックル等は「案」として出すだけ |

## Current concept

**SD-01「Bean head ＋ 同心ナックル」**（User が継続検討を承認。**CAD_CONCEPT / KINEMATIC_SIM**。Engineering の確認待ち）
**6 本目は暫定 Head Yaw**（H0 摩擦試験しだいで Body Yaw を再検討）。**CSAR は User 採用**

- 最重要原則への答え: **「見つけたら、見せびらかさず、離れて、大人に知らせる。子どもが来たら、こっちを見てもらう。」**
  幼児は視線・指さしの先を見るので、発見の合図（物を見る・指す・物の横でとぐろ）は子どもを危険物へ連れていく。
  振る舞いの規則 CSAR（R1〜R5）にして、守る行為と「ペットが大人に知らせに来る」を同じ動きにした。

## Current geometry direction

- Fusion: **`Serpens_DESIGN_SD01_BEAN_KNUCKLE_CONCEPT_NOT_FOR_PRINT`**（Serpens フォルダ、2026-09-29 に新規作成。FW03 など既存 CAD は変更していない）
  - コンポーネント: HEAD / NECK / LINK1 / LINK2 / LINK3 / TAIL（外装の外形。中は詰まったまま、部品ではない）、
    REF（FW03 v6 から読んだ Engineering の参照箱 41 個、非表示）、SCENE（姿勢の絵用の硬貨）
  - as-built 回転ジョイント J1〜J5（yaw ±50°、J1 は**このファイルでは負が頭上げ**、0〜−45°）。LINK2 を固定
  - 描き出し: `../docs/design/renders/SD01_*.png`（巡回・発見・人を見る・子どもが近い・眠り、各 iso / top）
- 座標は CAD と同じ（mm、頭が −X、Z 床基準）。関節軸 X: J1 −181.8（Z32.35）、J2 −95、J3 0、J4 95、J5 190

## Head concept（H1 Bean）

- 幅 100（胴 92 より広い）× 高さ 74 × 長さ 78。平らなあご・丸い鼻先・盛り上がった頭頂。角を作らない（毒蛇の三角頭を避ける）
- 顔の造作 = センサー: カメラ = **ボタン鼻**（濃色の平窓 D14、Z30）、前 ToF = **鼻孔**（2 つの小窓、Z50）、
  斜め照明 = 下唇の影、ライン光 = **眉**（顔の面から 6 mm 以内、X −233〜−229、Z64〜70。それより後ろだと鼻先が近い床への光を遮る）
- 目: 径 24 の半球ドーム (−212, ±37, 60)、丸い瞳、まばたきせず光の強弱。WS2812B を虹彩リングへ移す提案
- 首: 幅 68（半幅 34）へ絞る。頭 yaw を足すなら首に置く
- 数値: 頭 93 g（ASSUMED）、J1 静的 0.020 N·m（ソフト上限 0.45 の 4.4 %）、視錐台への殻のかかりなし、目の見かけ面積は H0 の 2〜3 倍

## Body concept（B1 同心ナックル）

- 前の節の後端 = 関節軸まわりの円柱（半径 46。J2 は 34）、後ろの節の前端 = 半径 +4 の受け（唇 ±40°）、関節の上を後ろの節の丸い背板（半径 48 / 36）が覆う
- 挟み込み（2D の形の計算、KINEMATIC_SIM）: B0 卵殻は 10〜40° で側面のすき間が 22.6 → 8.8 mm と 8〜25 mm の帯を通って閉じる。B1 は 0〜50° で 4.0 mm 一定、V 溝 約 97°。
  **4 mm 一定は安全確定ではない**（公差・上下の板・ケーブル・指の模型での確認は未。Engineering 検証待ち、User Decision 3）
- **Fusion で見つかった収まりの問題**: B1 では各関節の後ろ 0〜46 mm（中段）が**前の節の円柱**になる。FW03 の電池・尾 MCU・ヒューズ・スピーカー／アンプが関節の継ぎ目をまたぐ（ENTRY-0011）。
  電装を約 20〜35 mm 後ろへずらすか、中段の円柱を小さく（半径 ≈ 32）して外側を段付きにする必要がある

## Surface concept

- 背 sage、腹・側面の下 40 %（Z ≤ 40）ivory、背線クリーム（幅 18、尾から鼻先まで。発見の構えで物を指す矢印）
- つや消し。警告色（赤黄黒の縞）・菱形・縦長瞳孔・三角頭・牙・S 字の鎌首は使わない
- 腹: 交換式摩擦インサートを腹板（横の段）形にする提案（幅 40、ピッチ 10 mm、Fusion に形だけ）。摩擦比は H0 クーポンで実測（OQ-0102）
- 尾: 赤い停止ボタン（D12）を濃色の輪 D18 に少し沈めて尾の上（Engineering の位置 X296）に

## Interaction concept

- **CSAR は User 採用（2026-09-29）**。MVP の流れ: 見つける → 再確認（撮影）→ 位置登録 → **少し離れる** → 保護者へ通知。子どもが近ければ子ども側を見る。危険物のそばのとぐろは MVP で不採用（遮蔽効果と誘導リスクは将来の実験）
- CSAR: R1 子どもが近い（2.0 m 以内または不明）間は物を見ない・指さない / R2 物の場所を目立たせない（撮影の閃光を含む）/
  R3 見つけたら離れる（とぐろ・生きたピンはしない）/ R4 まず保護者へ通知 / R5 子どもが来たら頭と目を子どもへ、物から外す
- Discovery Loop（子どもがいない時）: 気づく → 体ごと一直線に静止して撮影（表現用 LED 全消灯＝息を止めて見つめる）→ 周りを見る → 保護者を見る（短い明るい音）→ もう一度物 → 離れる
- 姿勢: 巡回 / 発見（一直線）/ 人を見る（J2 45°、J1 30°）/ 子どもが近い（J2 −50°、J3 −20°、物から約 70° 外す）/ 眠り（三日月、yaw 合計 180°）

## Open design questions

OPEN-SERPENS-DESIGN-001〜009（`open-questions.md`）。特に 004（CSAR の採用、Human Approval）、001（ライン光の位置）、003（目の作り、OQ-0101 次第）

## Engineering dependencies

ENTRY-0005〜0011（`integration-log.md`）: 首幅 68 の収まり / ライン光の眉位置 / WS2812B と撮影中の全消灯 / ナックルとケーブルの渡り・R04 廃止 /
ナックルと電装の位置（ENTRY-0011）/ CSAR の実行条件 / 6 本目は頭 yaw を首に（Design 意見）/ ローラーの隠し方と腹板クーポン

## Rejected directions

| 案 | 理由 |
|---|---|
| H0 Egg（現行） | 頭 < 首 < 胴、目が小さく横・上から見えない、前面が球でセンサーが収まらない |
| H2 Wedge（写実） | かわいさが落ちる。鼻先が低くライン光の縦基線が入らない。重心が J1 から遠い |
| H3 Cyclops（カメラ = 目） | 見張られている印象（保護者のプライバシーの感じ方）、常に下向きの視線、蛇らしさが消える |
| H4 Visor（黒い窓の顔） | 窓の内面反射で LED・カメラ・ToF の光が混ざる。ロボット顔になる |
| B0 卵殻 15 mm 間隔 | 挟み込み域（8〜25 mm）を通って閉じる。数珠・芋虫に見える |
| B2 重ね鱗 / B3 TPU ベローズ | すべる縁のせん断、部品点数 / 曲げ剛性・割れ・熱 |
| B4 ニット袋 | MVP では不採用（見えない所で布が噛む、熱、衛生）。「撫でる・持ち上げる」段階の研究候補 |
| 危険物の横でとぐろ・生きたピン | 子どもを物のそばへ呼び寄せる。5 サーボでは輪も作れない（yaw 合計 ≤ 200°） |
| 背板を胴より 2 mm 厚く出す（Fusion 初版） | 横から見て屋根の板が載ったように見えた → 胴の面と同じ高さにした |
| 眉のライン光を顔の面から 10 mm 以上下げる | 鼻先が近い床（38〜48 mm）への光を遮る（計算） |

## Fusion の状態（2026-09-29）

- `Serpens_DESIGN_SD01_BEAN_KNUCKLE_CONCEPT_NOT_FOR_PRINT`: 最後の正常保存はジョイント追加の直後。背板の作り直しの実行中に Fusion の API が応答しなくなり、以後の変更の保存状態は**不明**
- User Decision 6・7: 復帰したら上書きせず **Recovery copy として別名保存**し、元ファイル（最後の正常保存版）を保持する。背板の修正は Recovery copy の上で、状態を読み取ってから続ける

## Next experiments

1. （Fusion 復帰後）状態の読み取り → Recovery copy を別名保存 → 背板を胴と同じ高さに作り直す
2. 6 本目 = 暫定 Head Yaw の首の意匠（首 50 mm 延長に頭 yaw サーボ）。Body Yaw に戻っても頭・首を流用できる形に
3. 静止画の予備評価: H0 / H1 / H2（同じ色・角度）を human_pilot の尺度で（ai-outbox/experiments）
4. ENTRY-0011 は Engineering の回答待ち（段付きナックル r ≈ 32 は案として保持、確定しない）
5. 将来の実験候補: 「遮蔽としてのとぐろ」の遮蔽効果と誘導リスク（MVP 外）
6. 腹板インサートの形を H0 クーポンに入れる相談

## 更新（2026-09-29 後半、Continuous Design Mode）

- Fusion 復旧: 元ファイルは v6 のまま保持。Recovery copy `Serpens_DESIGN_SD01_BEAN_KNUCKLE_RECOVERY_20260929` で、背板を胴と同じ高さにし、J3〜J5 の背板を r45 に変更（r48 は隣と 1 mm 重なっていた）。NECK の外形トリムも掛け直し、J1 の頭と首を同心にした。3D 干渉は全関節の全範囲で 0（CAD_CONCEPT）。J1 の頭の後ろに閉じる溝が残る（ENTRY-0013）
- 派生案: SD-01A〜E を比較（`docs/design/results/parametric_2026-09-29.md`）。**CAD へ持ち込む上位は SD-01E（A と C の中間）と SD-01A**
- CSAR の振り付け: `docs/design/csar_choreography_2026-09-29.md`（状態 × 子どもの状況、UNKNOWN = NEAR 扱い、禁止候補、Engineering への数値の問い、OPEN-010）
- Head Yaw の評価、ENTRY-0011 の代替案 A〜G（Design の推し順は A → C → G＋E）、人の評価のフォーマット、backlog: `docs/design/sd01_variants_and_fallbacks_2026-09-29.md`
- 次: SD-01E の頭を Recovery copy に別コンポーネントで作る → 人の評価用の描き出し（`tools/fusion_render_set.md`）→ Head Yaw の首の意匠

## 更新（2026-09-29 夜）

- Fusion が一度戻った間に、Recovery copy（v4 で保存）へ **SD-01E の頭**を別コンポーネントとして追加（HEAD A は無変更、J1E ジョイントつき、既定は非表示）。人の評価用の描き出し 16 枚（A / E × 4 姿勢 × 横・真上）
- **J1 頭–首の入れ子 VISOR** を 2D で検討: いまの形は頭を上げると外から届くすき間が閉じる（25° から）。VISOR ならどの角度でも届く 8〜25 mm のすき間なし・重なり 0（KINEMATIC_SIM、ENTRY-0013 に追記）。**P0 の案として Engineering 待ち**
- 描き出しの途中で Fusion がまた応答しなくなった。正面・3/4 の撮り直しは次の Fusion 作業
- 次: (1) 正面・3/4 の撮り直し (2) VISOR を Recovery copy の別コンポーネントで形にする（元の首・頭は残す）(3) Head Yaw の首の意匠 (4) 目の光り方の絵

## 更新（2026-09-29 深夜）

- Recovery copy に追加（すべて別コンポーネント、元は無変更）: **SD-01E2**（顔の読まれ方の修正）、**MOUTH LINE**（E3 = E2 ＋ 横の口の線）、**VISOR**（NECK-V ＋ HEAD E2-V、J1 0〜45° で交差 0）
- 人の評価の画像: `docs/design/renders/eval/`（A / E / E2 / E3 × 姿勢 × 画角、同じ画角）
- **現在の Design の第一候補: SD-01E3（= E2 ＋ 口の線）＋ VISOR の J1 ＋ 同心ナックルの胴**（CAD_CONCEPT。人の評価・Engineering の判定待ち）
- 次: 芯の色、Head Yaw の首（VISOR の芯の前に頭 yaw サーボ）、ENTRY-0011 の A 案で電装を動かした絵

## 更新（2026-09-29 Engineering の回答を受けて）

- Engineering の回答: ENTRY-0015（ライン光は眉を推奨）・0004（あご LED 6 mm・カメラ 25°）・0019（照明を後ろへ）・0020（スキッドの沈み）・0021（CSAR を模擬で実装）。Design の回答は **ENTRY-0022**
- **OPEN-SERPENS-DESIGN-001 は解決**（眉の段、X −233〜−229）。首軸 → レンズ 50.3 mm（A）/ 52.3 mm（E 系）
- 6 本目 = Head Yaw の Design 上の理由は、ライン光の向け直しではなく **CSAR の視線**だけになった
- 照明: 頬の下（斜め）と口の線（通常）の左右 2 灯で、近/遠の照度比 40 → 15 倍・33 → 11 倍（`tools/light_placement.py`）
- Fusion: Recovery copy が一度閉じていた（v9 で保存済みを確認して開き直した）。`LIGHT+SKID option` を追加（v10）
- 次: そりを顎板の形に、VISOR の芯の色、Head Yaw の首、ENTRY-0011 の A 案の絵

## User Decision（2026-09-29 追加）の反映

- **USER-DEC-SERPENS-DESIGN-0002（CSAR の撮影）**: CHILD_NEAR では写真確認を延期、passive snapshot のみ可、後ろ向きではなく向きを変えて前へ離脱、reinspect_point、highlight_point は CHILD_NEAR の hazard に禁止 → `csar_choreography_2026-09-29.md` §7
- **USER-DEC-SERPENS-0003**: 対象 3 歳未満・Safety Envelope 6 歳以下（人体寸法は一次資料から、`child_anthropometry_sources_2026-09-29.md`）/ 接触の閾値は Engineering が導出 / **yaw 合計 145°（暫定）** / 機械式トルクリミッターは検証する Safety Layer / Safety 値は逐一聞かずに検証
- Design への影響: 眠りの三日月（180°）は使わない → **「首をかしげる」[50,45,30,20]（合計 145°）**を眠り・充電の案に（OPEN-011: Head Yaw を合計に含めるか）。関節の外形にトルクリミッターの厚みを見込む（Engineering の寸法待ち）

## USER-DEC-SERPENS-0004（Head Yaw と 145°）の反映

- 145° = Body Curvature Budget。Head Yaw は合計に入れないが独立した Safety Axis。3D enclosure / entrapment check は必須（Engineering）
- Design 側の sweep（ENTRY-0026）: **Design の提案は Head Yaw ±30°**（J3 の補助つきで CSAR の視線を満たす最小。眠りの見た目のために広げない）
- OPEN-SERPENS-DESIGN-011 は解決

## 更新（2026-09-30）HEAD INTAKE STUDY 01（User の依頼）

- 依頼: 巻き込みくちばし（TPU のランプ ＋ 11.5 mm の腕 ＋ 30×30×15 の空間）の試験片 A と頭部レイアウト。報告 `docs/design/intake_study/HEAD_INTAKE_STUDY01_report.md`、STL 6 点、Fusion `Serpens_FW02_HEAD_INTAKE_STUDY01_NOT_FOR_PRINT`（FW02 v5 の複製、元は未変更）
- 主な所見: 卵の頭には入らない（空間の 42〜66 % が外）/ Bean 頭なら 約 92 % 入る / hinge_h 12.0 だと腕がランプを削る（12.2〜12.4 以上で解消）/ 閉じた腕は入口の 2 mm の帯しか塞がない / スキッド・下向き ToF と衝突
- 安全・範囲の注意（User 判断）: PRODUCT.md「やらないこと: 物を拾う・回収する」（OPEN-012）、挟み込みの力（SAFETY_UNVERIFIED）、CSAR との整合。Design は PRODUCT.md を変えていない
- ENTRY-D-0002、OPEN-SERPENS-DESIGN-012 / 013

## 更新（2026-09-30 後半）すき間チェック（ENTRY-E-0003 (5)）

- `docs/design/gap_check_report_2026-09-30.md`。STL ボクセル検査（0.5 mm、外形のみ、スクリーニング）。**静止**: 実欠陥（背板の尖り・頭巾の溝・ポケット・J2 の低い板・尾の刃）を CAD で直した。残り 3 か所（頭と首の下の三日月 170 mm³、J4 の脇の V 入口、尾の先）
- **曲げた姿勢では「全角度で 5〜12 mm なし」が成り立たない**: 脇の V（幅 5〜12 mm の長さ ≈ 7.5/tan φ）。形では消せず、柔らかいカバー（FLANK SKIRT STUDY、次）か閉じる力の制限（Engineering）が要る。OPEN-SERPENS-DESIGN-014、ENTRY-D-0003
- Fusion Recovery 複製: 尾の腹の帯の刃（x ≥ 318、z < 6.5）を切り落とした（押し出しの切り取り）。頭 HEAD E2-V v2 の外観（セージ・アイボリー・ストライプ・目の黒）は未復元（名前のない体に鋼の外観）

## 更新（2026-09-30 夜）すき間チェックの続き（User 承認: FLANK SKIRT STUDY・r の範囲・頭と首）

- 報告 `docs/design/gap_check_report2_2026-09-30.md`、ENTRY-D-0004（**ENTRY-D-0003 の一部を訂正**）。
- **KNUCKLE DRUM（形の直し）を CAD に入れた**: J2〜J5 の玉の脇を z 8〜76 で完全な円柱（R 46、J2 は R 34）に戻す。胴の層のすき間 約 90 % 減（p1 6807 → 2558）。外観は関節に「膝」ができる（人の評価が要る）。既存の外側に足す体積は 11〜13 cm³/個
- 頭の下の後ろの埋め物（`E2-V lower-rear fill`）で p0 のすき間 172 → 2 mm³
- **FLANK SKIRT STUDY**: 脇のフラップの概念 CAD と運動学モデル。**すき間は減らず増えた**ので採らない（上下まで閉じる袖状のカバーは未設計）。唇・あごのフラップも効かなかった
- 残り: 背板の層 z ≥ 77（約 1020 mm³/姿勢）、J1 ピッチ（−5° で 601、+22° で 4307 mm³）、J2 の背板の層
- r の範囲: J3〜J5 は r = 42.5〜50 mm の輪、J2 は 28〜49、J1 はピッチで変わる

## 更新（2026-09-30 深夜）KNUCKLE DRUM 承認・試験片・試験片 B

- User 承認: KNUCKLE DRUM を進める。**レポートの冒頭に「まっすぐ比 約 20 倍の体積が残る」を書き続ける**（`gap_check_report*.md`、`mass_addendum`、試験片 README、ENTRY に反映）。背板の層は未解決のまま、J1 ピッチは動作範囲の回答待ち
- 円柱肩の試験片 R46 / R34（`docs/design/knuckle_test/`）、質量は中実（最大）61.1 g / 中空 55.8 g（`mass_addendum_2026-09-30.md`）
- 試験片 B（`docs/design/test_piece_b/`）: 漏斗つきフード ほか。**段差の解釈は Design の仮定**
- Fusion: Recovery 複製に `KNUCKLE TEST R46/R34 …`、FW02 intake の複製に `TEST PIECE B1 …`（元は未変更）

## 更新（2026-09-30 夜）試験片 B2・頭への統合・背板 2 案・J1 範囲

- **先頭の注意**: 現行 CAD（KNUCKLE DRUM のみ）は、まっすぐ比で約 20 倍のすき間の体積が残る。背板は現行 CAD では未解決のまま（案は別コンポーネント）。J1 は範囲の確認待ち
- `test_piece_b/B2/`（t と c を独立）、`head_intake_e3/REPORT.md`、`plate_layer_2026-09-30.md`（(a) DRUM-FULL / (b) 同心ドーム、J2〜J5 は p1 で 1373 → 52 / 71）、`j1_pitch_2026-09-30.md`（作業窓 −2〜+1°）
- Fusion: Recovery 複製に `HEAD INTAKE on E3 STUDY`、`PLATE VARIANT A/B`。FW02 intake 複製に `TEST PIECE B2`。元は未変更
- ENTRY-D-0006

## 更新（2026-09-30 深夜）口の前の配置・ENTRY-D-0006 への回答

- **先頭の注意**: 現行 CAD（KNUCKLE DRUM のみ）は、まっすぐ比で約 20 倍のすき間が残る。背板は未解決、J1 は範囲の確認待ち
- `mouth_front_layout_2026-09-30.md`: 口の前の禁止域に入る部品 15,290 mm³ → 案 0。c は床から（シミュのコード）。B2 の板は訂正（`B2/CORRECTION_2026-09-30.md`）。J1 の取り込み窓 −0.1〜+0.9°。照明: 斜めを口の前の角へ移すと 15 → 35 倍
- **Fusion 切断のため CAD 未変更**（スキッド・ToF・LED の移動は次回）。ENTRY-D-0007

## 更新（2026-09-30 深夜）ENTRY-D-0006 の 4 点への回答（ENTRY-D-0008）

- **先頭の注意**: 現行 CAD（KNUCKLE DRUM のみ）は、まっすぐ比で約 20 倍のすき間が残る。背板は未解決、J1 は範囲の確認待ち
- `engineering_answers_2026-09-30.md`: c は床から（確定）、J1 の窓は取り込みで 12 ステップ・受動の柔らかさは成り立たない（床接触の較正が要る）、VL53L1X は 4 cm 未満は不正確・±20〜25 mm で数 mm は測れない、斜め LED は **横スキッドの前端**が最良（巡回 0.94、17.4 倍）

## 更新（2026-09-30 夜）B2 の印刷セット・回答の位置づけ訂正・フード昇降（ENTRY-D-0009）

- **先頭の注意**: KNUCKLE DRUM 後も、まっすぐ比で約 20 倍（18〜24 倍）のすき間が残る。背板は現行 CAD では未解決のまま。5.7 N・0.25 N·m は暫定（SAFETY_UNVERIFIED）。安全・合格の語は使わない
- **B2 は User が印刷中（2 日間、結果は待たない）**: `test_piece_b/B2/PRINT_LIST.md`、`T0p05_HOWTO.md`、`B2_test_log_template_v2.csv`（t = 0.05・4 分類・動画名）。**印刷待ち**: 実測厚さ・エレファントフット・0.05 の貼り方の浮き。B2 の結果を前提にしたフードの大きな変更は入れない
- `engineering_answers_2026-09-30.md` は **Design の見積もり（Engineering 未検証）** に位置づけを訂正（追記 + §6 の確認依頼）。D-0007 / D-0008 の「確定」は同じ意味で読み替え
- `hood_lift_2026-09-30.md`: s = 5 まで頭 E3 に入る（あご +13.9 cm³、J1 サーボ 792 mm³ は要確認）、8・10 はカメラと J1 サーボに当たる。J1 は使わない
- **Fusion 待ち（まとめて実行）**: スキッド・ToF・斜め LED の移設、背板 (b)、J1 の箱形カバーとストッパー、フード昇降の CAD

## 更新（2026-09-30 夜、Fusion 復帰後）CAD 反映と J1 符号の訂正（ENTRY-D-0010）

- **先頭の注意**: KNUCKLE DRUM 後も、まっすぐ比で約 20 倍（18〜24 倍）のすき間が残る。背板は現行 CAD では未解決のまま。5.7 N・0.25 N·m は暫定（SAFETY_UNVERIFIED）。安全・合格の語は使わない
- **J1 の符号**: CAD のラベルは + が頭を下げる。Engineering の符号では、範囲の端は −5° = 401、+10° = 1562 mm³、作業窓 −2〜+1° は最大 40 mm³（`j1_sign_correction_2026-09-30.md`）
- 上の輪の覆い（別コンポーネント、STL あり）で −5° 401 → 29。下のくさびは形で埋まらない（+3° に狭める / 動く覆い）
- Fusion に別コンポーネントを追加（`MOUTH FRONT LAYOUT STUDY 01`、`HOOD LIFT STUDY 01`、`J1 COVER + STOPPER STUDY 01`）。既存は未変更、保存済み

## 更新（2026-09-30 夜）頭 E3 の統合版（ENTRY-D-0011）

- **先頭の注意**: KNUCKLE DRUM 後も、まっすぐ比で約 20 倍（18〜24 倍）のすき間が残る。背板は現行 CAD では未解決のまま。5.7 N・0.25 N·m は暫定（SAFETY_UNVERIFIED）。安全・合格の語は使わない
- User の許可（組み替えてよい、デフォルメ調でかわいく）で `HEAD E3 INTEGRATED v1 - cute deformed` を別コンポーネントで作成（元は残す）。あご −56.5 cm³（−34 %）は Engineering の確認待ち

## 更新（2026-09-30 夜、自律運用）ストッパー v2・覆い 3 案・ToF 基板・フード昇降 3 案・統合版 v2（ENTRY-D-0012）

- **先頭の注意**: KNUCKLE DRUM 後も、まっすぐ比で約 20 倍（18〜24 倍）のすき間が残る。背板は現行 CAD では未解決のまま。5.7 N・0.25 N·m は暫定（SAFETY_UNVERIFIED）。安全・合格の語は使わない
- R-003: 窓 φ 30.51〜48.49°（パッド 3 mm）、鋼ダウエル φ3 × 10.5 + TPU パッド 3.0×3.6×2.0。θ_E +4° = 151、−4° = 覆いなし 319 / 覆いあり 23（E-0011 の補間 205 は過小）。窓・穴は HT-001 の後に切る
- 覆い 3 案（A 推奨・安全側）: User の見た目の判断待ち（R-011）
- R-007: ToF 小基板は「肉球」（横スキッド前端を広げる、|y| 51.6）。後ろは不可。スキッド底は足の帯の底より c₀ 0.1 mm 低い
- R-005: フード昇降は s = 4、推奨 L2（TPU 板ばね耳 1.2 N、prior）
- Fusion: `HEAD E3 INTEGRATED v2`（あご −32.7%）ほか追加。v1・元は残し非表示。HARDWARE_TODO に HT-008〜011 追記
- **待機の条件**: User の覆いの判断（R-011）と Engineering の返信（R-012）が来たら再開。B2 は印刷待ち

## 更新（2026-09-30 夜）覆いは案 A に決定（ENTRY-D-0013）

- User が案 A（8° の殻）を採用。`J1 COVER A ADOPTED`（Fusion、STL あり）。次: 襟への接合の設計、Head Yaw との干渉、B2 の印刷待ち

## 更新（2026-09-30 夜）覆い A を襟と一体化・v2 の質量と重心（ENTRY-D-0014）

- 待機せずに進めた: `NECK-V v4 with COVER A`（一体）、v2 の質量・重心（SG90 の +y 偏り 約 2.8 mm → ダミー質量を推奨）。Head Yaw は MVP の外

## 更新（2026-09-30 夜）Engineering E-0012〜E-0014 への回答（ENTRY-D-0015）

- **先頭の注意**: KNUCKLE DRUM 後も、まっすぐ比で約 20 倍（18〜24 倍）のすき間が残る。背板は現行 CAD では未解決のまま。5.7 N・0.25 N·m は暫定（SAFETY_UNVERIFIED）。安全・合格の語は使わない
- 訂正: E 3 MPa 撤回（P1 既定、P2 の STL も）、ダミー質量撤回。+6〜+9° は 1270〜1714 mm³（補間より 33〜74% 大）。頭の質量は殻でも 137〜234 g で 90 g 予算超過（Design の薄肉化が課題）。フードの端の 1 ビット = 磁石 + ホール（HT-013）
- **待機**: 実機・印刷待ち（HT-001 / 007 / 008 / 009 / 012 / 013）。Design の次の課題（急がない）: 頭の薄肉化（90 g）、背板 (b) のかわいい形、襟の覆いの印刷向き

## 更新（2026-10-01）印刷リストをまとめた（ENTRY-D-0016）

- `docs/design/print_all/PRINT_LIST_ALL_2026-10-01.md`（P0 B2 → P1 HT-008/009 → P2 HT-010/011 → P3 KNUCKLE 任意）。ToF 基板の長さ 18 mm に CAD を訂正、ポケット上開き
- 待機: 印刷・実機待ち

## 更新（2026-10-01）軌跡の文書を作成（ENTRY-D-0017）

- `ai-shared/PRODUCT_HISTORY.md`（以後 ENTRY ごとに §9 へ追記）。待機: 印刷・実機待ち

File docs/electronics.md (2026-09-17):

# 電子系 — ブロック図・電力の見積もり・部品表の骨格（設計案。HARDWARE_UNVERIFIED）

作成 2026-09-18。**回路図も基板も部品も無い。** この文書は `ELECTRICAL_SAFETY_GATE`
（`docs/safety_limits.md` §5）の 8 項目を「何をどう測れば埋まるか」まで落とすための骨格。
数値は出典を書く。出典が無いものは **UNKNOWN** のまま置く（推定で埋めない）。

## 1. ブロック図（案）

```
[12V テザー] ─ ヒューズ ─ [電源分配]
                             ├─ DC/DC 5V ─ [XIAO ESP32-S3]（駆動リンク・歩容・watchdog）
                             │                 │ UART 1M bps（半二重）
                             │                 ↓
                             ├─ **遮断器** ─ [サーボバス V+] ─ STS3215 ×9（デイジーチェーン）
                             │      ↑
                             │   [安全 MCU or ハード watchdog]  ← 物理 E-STOP（直列・常閉）
                             │      ↑                              ← 電流検出（バス全体）
                             │   ESP32 の「生きている」パルス（heartbeat 出力）
                             └─ DC/DC 5V ─ [頭部 XIAO]（ToF・タッチ・LED。既存の行プロトコル）
```

要点（憲章 16章 層2）:

- **サーボの電源を切る経路を ESP32 に依存させない。** 遮断器（リレー or ハイサイド MOSFET）は
  安全 MCU（またはリトリガ型ハード watchdog）が駆動し、ESP32 のパルスが止まれば切る。
  ファームが暴走しても、PC が死んでも、電源が落ちる。
- **物理 E-STOP は遮断器の駆動回路に直列**（ソフトを介さない）。常閉接点で、抜けても止まる側へ。
- 電流検出はバス全体で 1 箇所（まず十分）。閾値は実測後（§2）。
- 12V → サーボ V+ の間に **C044 の最高入力電圧（8.0V 初期値。`docs/sts3215_registers.md`）に合う電圧**
  が要る。12V を直結してはいけない。7.4V を作る DC/DC（容量は §2 の実測後）か、電源そのものを変える。

## 2. 電力の見積もり — 出典ごとに分ける

| 値 | 数値 | 出典 | C044（7.4V / 1:191）に使えるか |
|---|---|---|---|
| ST3215 入力電圧 | 6〜12.6V | Waveshare Wiki ST3215_Servo（2026-09-18 閲覧） | 電圧範囲は同型番の記載。**C044 の上限は要確認** |
| ST3215 ストール電流 | 2.7A | 同上（電圧の記載なし。30kg·cm@12V の品） | **使えない**（12V 品の値） |
| ST3215 無負荷電流 | 200mA | 同上 | **使えない**（同上） |
| C044 ストール電流 / 無負荷電流 / 待機電流 | **UNKNOWN** | 一次資料なし | 実測で埋める |
| 定格トルク（参照） | 5.2 kgf·cm | CAD 資料（`config/robot.yaml` servo） | 参照値。実測ではない |

**だから電源容量・ヒューズ定格・遮断閾値はまだ決められない。** 決めるのに要る実測:

1. C044 1 個の無負荷電流・保持電流・ストール電流（7.4V、電流計直列）→ `real_current`
2. 9 個の同時起動時の突入電流（オシロ + シャント）→ `power_capacity`
3. 歩容（FAST / SMOOTH の候補）を模擬負荷で 10 分回したときの平均・ピーク電流と配線温度 → `wiring_heat`

見積もりの**枠だけ**書くと（値は入れない）:
`I_supply ≥ N × I_stall(C044)` が最悪、`I_typ ≈ N × I_hold + 歩容の変動` が通常。
ヒューズは `I_typ` の余裕上、`I_supply` の下。すべて実測後に埋める。

## 3. ゲートの各項目をどう埋めるか

| ゲート項目 | 測り方 / 作り方 | 必要な物 |
|---|---|---|
| real_current | §2 の 1 | C044 ×1、7.4V 電源、電流計 |
| power_capacity | §2 の 2 | C044 ×9、シャント、オシロ |
| overcurrent_protection | 意図的にストールさせ、ヒューズ/電子遮断が**実際に**切れることを見る | ヒューズ or 電子遮断の候補 |
| wiring_heat | §2 の 3。コネクタ温度を熱電対で | 熱電対 |
| independent_power_cut | §1 の遮断器を作り、ESP32 のパルスを止めて切れることを見る | 安全 MCU or watchdog IC、リレー/MOSFET |
| physical_estop | 押したら遮断器が切れる。ケーブルを抜いても切れる（常閉） | E-STOP スイッチ |
| servo_temperature | 連続運転で温度レジスタ（番地 63）と実温度を比べ、60℃ で機体が止まることを見る | 熱電対 |
| real_stop_time | 緊急停止・通信断から出力が止まるまで。オシロでサーボ電流 or 位置を見る | オシロ |

## 4. 部品表（骨格。品番は未選定）

| 区分 | 候補の種類 | 状態 |
|---|---|---|
| MCU（駆動） | XIAO ESP32-S3（ファームは `firmware/serpens_esp32`。コンパイル済み・未書き込み） | 決定済み（憲章） |
| MCU（頭部） | XIAO（既存の行プロトコル） | 決定済み |
| 安全 MCU / watchdog | 独立の小型 MCU またはリトリガ型 watchdog IC + リレー/MOSFET | **未選定** |
| サーボ電源 | 7.4V を作る DC/DC（容量は §2 後）またはバッテリ | **未選定・電圧が先に決まる** |
| 電流検出 | ハイサイド電流センサ（範囲は §2 後） | **未選定** |
| 物理 E-STOP | 常閉のキノコ型スイッチ | **未選定** |
| IMU | 憲章が「持ち上げ検知」に要求。未着手（`docs/safety_limits.md` §3） | **未選定** |
| 配線 | サーボバス（3線）、電源、USB | 経路は機構担当と |

## 5. 決めていただくこと

1. サーボ電源: 12V テザーから 7.4V を作るか、7.4V 系（2S 相当）を引くか。
2. 安全 MCU を置くか、watchdog IC + リレーで済ませるか（安全 MCU は電流閾値を賢くできるが部品と firmware が増える）。
3. 部品の購入順（§3 の 1 → 2 → 3 の順で C044 1 個から）。

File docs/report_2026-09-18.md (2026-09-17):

# 作業レポート 2026-09-18 — 実機なしでソフトだけで進めたこと

前提: 実サーボ・ESP32・実カメラは 1 台も無い。**実サーボ操作・EEPROM 変更・ファーム書き込みは行っていない。**
`HARDWARE_VERIFIED` は引き続き **0 件**。検証レベルの意味は `docs/verification_status.md`。

## 1. 完了したもの

| # | 内容 | 検証レベル | 根拠 |
|---|---|---|---|
| 1 | **実画像経路の観測器 `CameraObserver`**（カメラ番号 / 動画 / 静止画 → デコード → ArUco → 床座標 → 自己位置・人）。`--camera` で `serpens.app` に接続。旧 `RealCamera`（人だけ渡していた）を置き換え | `SIMULATED` | `tests/test_camera_observer.py`（5）。仮想カメラの画像を **MJPG 動画に書き出して読み直し**、圧縮・デコード・ファイル入力を通した。首の位置誤差 p95 < 25mm、検出率 ≥ 90% |
| 2 | 録画（`aruco_file`）は実機の開始条件を満たさない。生きたカメラ（`aruco`）だけが満たす | `SOFTWARE_VERIFIED` | 同上。録画を再生しながら実機を走らせる事故を防ぐ |
| 3 | **見失った後（と最初）の自己位置は、人が K キーで確認するまで走行に使わない**（`acknowledge_pose`）。偽マーカで再取得した位置のまま走らないため | `SOFTWARE_VERIFIED` | `tests/test_vision_bridge.py`、`test_camera_observer.py` |
| 4 | **制御周期の実測**（`tools/loop_timing.py`）: 50Hz 目標に対し、仮想カメラ描画スレッド同時で平均 19.96ms / 最悪 20.7ms / 遅れ 0/502。**ArUco + YOLO（1枚 59ms）スレッド同時でも** 平均 19.96ms / 最悪 20.9ms / 遅れ 0/502 | `SOFTWARE_VERIFIED`（このPC） | 実測。ただし PC 固有。展示用 PC で測り直す |
| 5 | **電子系の設計案** `docs/electronics.md`: ブロック図（ESP32 に依存しない遮断器 + 常閉 E-STOP + 電流検出）、ゲート 8 項目の測り方、BOM の骨格 | 設計案のみ | 一次資料 Waveshare Wiki（2026-09-18）。**12V 品の 2.7A / 200mA は C044 に流用せず、C044 の電流は UNKNOWN** と明記 |
| 6 | `serpens/app.py` を 313 行 → 233 行（300 行制限へ戻した） | — | — |

全 **352 件**のテストが通る（`.venv/Scripts/python.exe -m pytest -q`、約 130 秒）。

## 2. 直前の 2 コミット（2026-09-16、参考）

- `efec2c9` ELECTRICAL_SAFETY_GATE（8 項目、全 INCOMPLETE）を実機自律走行の開始条件へ。接触→脱力の要求整理
- `de4628b` Phase 4: 模擬画像の Vision で閉ループ。見失い時の保持、重複 ID・位置の飛びの棄却

## 3. 見つけた問題と判断

- **録画ファイルは既定でループ再生**（`VideoFileSource(loop=True)`）だった。観測器では位置が先頭へ飛ぶので
  ループを切った（終わったら「観測なし」→ 0.5s で保持）。
- 実カメラでは **YOLO の初回推論が 2.4 秒**かかる（重みの読み込み）。起動直後 2 秒は人が見えない。
  観測器の構築時に 1 枚だけ先に通す方が親切だが、今日はやっていない（起動時間が延びるだけで安全には影響しない）。
- 制御周期は知覚スレッドと同時でも遅れなかった。**ただし GIL の下で 59ms の推論が走っているので、
  展示用 PC が非力なら遅れる。** `tools/loop_timing.py` をその PC で回すこと。

## 4. できなかったこと（ハードが要る）

| 項目 | 理由 |
|---|---|
| C044 の電流（無負荷・保持・ストール・突入） | 一次資料に無い。サーボ 1 個の購入と電流計が要る。電源容量・ヒューズ・遮断閾値はこれ待ち |
| 実カメラでの誤差・遅れ | カメラが無い。`--camera 0` と `tools/calibrate_floor.py` の校正で即日測れる形にはなっている |
| 接触→脱力（20ms） | 要求（何を接触とみなすか等 Q1〜Q5）が未確定。`docs/contact_release_requirements.md` |
| ファームのサーボ層 | ESP32 とサーボバスの配線方式が未決定。書けてもコンパイルまで |
| 脱力で挟み込みが解けるか | 1:191 のバックドライブトルクは実測が要る |

## 5. 決めていただくこと

1. サーボ電源: 12V テザーから 7.4V を作るか、7.4V 系を引くか（`docs/electronics.md` §5）
2. 安全 MCU を置くか、watchdog IC + リレーで済ませるか
3. 購入順: **C044 1 個 + 電流計**が最優先（ゲートの `real_current` と設計の全数値が待っている）
4. 接触→脱力の Q1〜Q5（`docs/contact_release_requirements.md` §1）
5. 見失い後の再開を「人の K 確認 → G」にした運用でよいか（来場者がマーカを隠すたびに操作が要る）

## 6. 次にソフトだけで進められること

1. 実カメラ用の校正手順（`tools/calibrate_floor.py`）を `CameraObserver` と同じ入力元で通せるようにする
2. `CameraObserver` 構築時に YOLO を 1 枚ぶん温める（起動直後の 2 秒の空白を無くす）
3. 展示用 PC が決まったら `tools/loop_timing.py` を回す
4. ファームのサーボ層は、配線方式が決まった時点で Feetech プロトコルの送受信をコンパイルのみで用意

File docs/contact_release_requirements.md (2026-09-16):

# 接触 → 脱力 20ms — 要求の整理と機体側の設計案

作成 2026-09-16。**状態: 未達（NOT ACHIEVED）。** 実装より先に、要求そのものが決まっていない。
この文書は「何が決まっていないか」と「決まったらどこで実装するか」を分けて書く。

出典: 構想設計書 16章（`safety_limits.contact_release_ms: 20`）。
現状: PC 側の `behavior.safety.grab_load_ratio`（0.75）が `grab_hold_s`（0.8s）続いたら PETTED。
**約 800ms。しかも PC が生きていることが前提。**

## 1. 決まっていないこと（要求の穴）

| # | 問い | 現状 | 決める人 |
|---|---|---|---|
| Q1 | **何を「接触」とみなすか。** 指の挟み込み / 胴体を握られた / 何かにぶつかった / 持ち上げられた | 区別していない。PC 側の「掴まれた」だけ | 製品（ユーザー） |
| Q2 | **何で検知するか。** サーボの現在負荷 / 位置偏差 / 電流センサ / タッチセンサ / 圧力センサ / IMU | サーボ負荷（番地 60）のみ。**これは PWM のデューティ比で、力ではない**（`docs/sts3215_registers.md`）。符号ビットも仮説 | 電子系 + 実測 |
| Q3 | **反応は HOLD か TORQUE_DISABLE か。** | 未定。下の §2 のとおり、どちらも挟み込みを解かない可能性がある | 機構 + 製品 |
| Q4 | **どの部位を対象にするか。** 胴体の関節すき間 / 頭部 / 首（J7 は重力で落ちる） | 未定。J7 を脱力すると頭が落ちる | 機構 |
| Q5 | **20ms は何を根拠にした値か。** 検知まで？出力停止まで？力が抜けるまで？ | 構想設計書に数値だけがあり、区間の定義と根拠が無い | 製品（出典の確認） |
| Q6 | **誤検知をどこまで許すか。** 歩容中の自己負荷（MuJoCo で飽和率 ~12%, SIMULATED）と区別できるか | 未評価 | 実測 |

## 2. 物理の側で先に確かめること（HARDWARE_UNVERIFIED）

- **STS3215-C044 のギア比は 1:191。** 脱力しても外から関節を回すのに要るトルク（バックドライブ）が
  **未測定（UNKNOWN）**。高減速比のサーボは脱力しても「固いまま」のことがあり、
  その場合 TORQUE_DISABLE は挟まれた指を解放しない。**脱力が解放になる前提を置かない。**
- 挟み込みを解くには「逆に少し動かす（後退）」が要るかもしれない。これは能動動作なので、
  誤検知時の危険と天秤になる（Q3）。
- J7（首ピッチ）は脱力で頭が落下する。対象から外すか、保持にするかを決める（Q4）。

## 3. 20ms の時間予算（計算値。実測ではない）

1M bps・8N1 では 1 バイト ≈ 0.01ms（`docs/sts3215_registers.md` の通信仕様から計算）。

| 区間 | 見積もり | 根拠 / 未確定 |
|---|---|---|
| 負荷の読み出し（SYNC READ 0x38 から 8 バイト × 9 軸） | 要求 17 + 応答 14×9 = 143 バイト ≈ **1.4ms** + 応答遅延 | 応答遅延（番地 7）の実値は **UNKNOWN**。SYNC READ 非対応なら個別 READ で約 9 倍の往復 |
| 判定（しきい値・連続回数） | 制御周期 10ms × **k 回** | k=1 だと誤検知に弱い（Q6）。k=2 で **最悪 20ms を使い切る** |
| 脱力の書き込み（SYNC WRITE 番地 40 × 9 軸） | 26 バイト ≈ **0.3ms** | 応答なし |
| サーボ内部で出力が落ちるまで | **UNKNOWN** | データシートに記載なし |
| 力が実際に抜けるまで | **UNKNOWN** | §2 のバックドライブ次第 |

読み方: **通信だけなら 20ms に収まる計算になるが、判定の連続回数を 2 回にした時点で余裕が無い。**
PC を経由すると、テレメトリ 10Hz（100ms）と USB 往復が乗るので**原理的に届かない**。

## 4. 設計案 — 機体（ESP32）側で閉じる

```
100Hz 制御周期（firmware の control()）
  readServos()                       ← 負荷・位置を読む（いまは空関数）
  contactCheck()                     ← 新設。PC の判断を待たない
     |load| > contact_load_ratio を k 周期連続     （Q2・Q6 が決まるまで値は置かない）
     or |目標 − 実測| > contact_pos_err_deg を k 周期連続
  → 反応（Q3 で決める）: HOLD or TORQUE_DISABLED
  → EVENT を PC へ通知（通知は後。止めるのが先）
  writeServos()                      ← 反応後の出力
```

- **ラッチ扱いにする**: 接触での停止は `EMERGENCY_LATCHED` と同じく、原因が消えても自動復帰しない。
  CLEAR_FAULT → DISARMED → 明示 ARM の段差を保つ（`CLAUDE.md` の安全設計）。
- 設定は `link.faults` に置き、**ファームと Python の値の一致を `tests/test_firmware_sync.py` で検査**する。
- 仮想機体（`serpens/link/device.py` の `_watchdogs`）に同じ判定を足せば、PC が止まっていても
  脱力することを SIMULATED で試験できる。ただし**しきい値は実測が無いと決められない**ので、
  現時点では実装しない（無意味な既定値でスイッチだけ作ると「実装済み」に見えるため）。

## 5. 実装に進む条件

1. Q1〜Q5 が決まっている（製品・機構の判断）
2. 実サーボで、歩容中の負荷分布と、指を模した荷重をかけたときの負荷を測ってある（Q6）
3. 脱力時のバックドライブトルクを測ってある（§2）
4. `ELECTRICAL_SAFETY_GATE`（`docs/safety_limits.md` §5）の「実停止時間」が測れる環境がある

それまでは PC 側の 800ms の経路が唯一の経路であり、**`contact_release_ms: 20` は未達のまま表示する。**

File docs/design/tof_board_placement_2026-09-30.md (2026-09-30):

# VL53L1X 小基板の載せ位置（R-007）— 横スキッド前端

> **先頭の注意**: KNUCKLE DRUM 後も、まっすぐ比で約 20 倍（18〜24 倍）のすき間が残る。背板は現行 CAD では未解決のまま。5.7 N・0.25 N·m は暫定（SAFETY_UNVERIFIED）。安全・合格の語は使わない。
> 数値の出典: 基板寸法 = **User の依頼（幅 12、高さ 3.2）**、**長さ 18 は ASSUMED**（実物で確認 = HARDWARE_TODO HT-011）。位置・寸法 = **CAD_CONCEPT**。ToF の役割・置き場所 = **Engineering（ENTRY-E-0008 (3)）: 用途は崖の 2 値。横スキッドの前端（左右 2 個）。後ろのスキッド 2 つの間は不可**。**Design の見積もり（Engineering 未検証）**。
> 図: `assets/tof_board_options_2026-09-30.png`、Fusion `TOF BOARD PLACEMENT STUDY 01 (R-007)`。

## 0. 結論

1. **推奨は案 S2「肉球」**（横スキッドの前端を丸く広げて、基板をその中に収める）。**S1（外付け）は頭の最大幅 ±50 を超えて ±58 まで張り出す**が、S2 は ±51.6 で済む。
2. **前回（ToF を後ろのスキッド 2 つの間）は Engineering の指摘（E-0008 (3)）で不可**。**Fusion の統合版の ToF の窓（後ろ）は、この結果に従って前端へ移す**（次の CAD 更新）。
3. **スキッド底と足の帯の底は、同一面ではない。スキッドの底が c₀ = 0.1 mm だけ低い**（`mouth_front_layout` §3）。**同一の加工基準面**（ガラス板上でやすり掛け）から、スキッドの底を 0.1 mm 下に残し、足の帯を切る。**4 つのスキッド底（左右の前・後ろ）の高さの差は ±0.05 mm 以内**（やすり掛け）。

## 1. 基板の仮定（[B] 依頼 / [A] ASSUMED）

- 幅 12 mm（y）、高さ 3.2 mm（z、はんだ面 + センサー）、**長さ 18 mm（x、ASSUMED）**。センサーは下向き（床を見る）。ポケットは基板 + 0.2〜0.4 mm の余裕。
- ToF は**崖の 2 値**（VL53L1X の最短 4 cm 未満は検出するが不正確。床までの距離 3 mm は無効側、崖 60 mm は有効側 = E-0008）。**c・t（0.1 mm 単位）の測定には使わない**。

## 2. 2 案の比較

| | 案 S1: 外付け | **案 S2: 肉球（推奨）** |
|---|---|---|
| 形 | 横スキッド外面（|y| 44）に 2 mm の板、基板 12×18 が外へ | 横スキッド前端を丸く広げる（半径 7.8、|y| 36〜51.6、x −229.8〜−202.2）。基板は穴の中（|y| 37.8〜49.8、z 3.0〜6.2）、底に窓（|y| 40.8〜46.8） |
| 頭の外側への張り出し | **|y| 58**（頭の最大 ±50 を 8 mm 超える） | **|y| 51.6**（1.6 mm 超える。あごの下の張り出しは 14.8 mm） |
| センサー窓の位置 | x −226〜−208、口の面から 10〜28 mm 後ろ（E-0008: 11〜24 mm）| x −223.5〜−207.5、口の面から 12.5〜28.5 mm 後ろ |
| 床からの高さ | 2.8（窓）| 3.0（窓）。**床まで 3 mm（40 mm より近い = 崖の判定は「無効 / 有効」の 2 値）** |
| 頬のレンズ（LED）| スキッドの前端（X −226、|y| 40、z 3〜6）のまま | 肉球の前端（X −228、|y| 40、z 4.5）。**基板の窓と LED は同じ足の中** |
| 質量（PLA、目安）| 板 + ブラケット 約 1.1 g / 側 | 肉球の増分 約 1.2 g / 側（体積 2,927 mm³ − 元のスキッド前端）|
| 強度 | ブラケットが片持ち（12 mm 張り出し）で弱い | 肉球は あごの底（|y| 36〜44、z 10 以上）に接合。**|y| 44〜51.6 は 7.6 mm 張り出し**（未検査）|
| 見た目 | 基板が丸見え（無骨） | **丸くて足のよう（デフォルメ調に合う）** |
| 挟み込み | 板と頭のすき間 0.3〜9 mm のくさび（頭が動くときの相対運動なし。J1 は頭全体が動く）| 肉球とあごのすき間 9 → 0 mm のくさび（同じ。相対運動なし）|

## 3. 確認したこと

- **口の前の禁止域（|y| ≤ 34、口の面〜奥の壁の外、z ≤ 16.6）**: S2 の肉球は |y| ≥ 36 なので 0 mm³（足の帯 |y| 34 との間 2 mm）。S1 も 0。
- **ToF の視野 27° と頭の陰**: センサーが床から 3 mm で、視野の床の径 = 2 × 3 × tan 13.5° = 1.4 mm。**頭の陰・フードの陰は入らない**（口の前 12.5 mm の横）。
- **斜め LED との干渉**: 基板の窓（x −221〜−213、y 40.8〜46.8）と LED（x −228、|y| 40）は 5 mm 以上離れる。**LED の光が基板に当たる（反射）恐れは未確認**（実写 = HT-005 の T4）。
- **J1 = 0° のとき**: 肉球の底 = スキッドの底（同一の加工面）。

## 4. 未確認

- 基板の長さ、窓の位置、配線の取り回し（HT-011）。肉球の張り出し 7.6 mm の強度。**ToF の崖判定が実機で成り立つか（T6-1〜T6-4）は Engineering の試験**。

## 5. 訂正（2026-10-01）

- **基板の長さ**: 文書は 18 mm（ASSUMED）だったが、CAD の基板は 16 mm だった。**CAD を 18 mm（x −224.7〜−206.7）に直し、ポケットを 18.4 mm（x −225.0〜−206.6）にした**。
- **ポケットは上を開けた**（z 2.9〜10.5）。基板を上から入れ、あごの底（または蓋）で押さえる。閉じた箱では基板が入らない。実寸合わせ用の試験片は `print_all/P2_HT011_tof_paw_fit/`（ポケット 18.4 / 20.4 mm）。

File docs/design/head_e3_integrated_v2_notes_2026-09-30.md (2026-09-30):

# 頭 E3 統合版 v2 と覆い A の接合 — 質量・重心・接合の見積もり（2026-09-30 夜）

> **先頭の注意**: KNUCKLE DRUM 後も、まっすぐ比で約 20 倍（18〜24 倍）のすき間が残る。背板は現行 CAD では未解決のまま。5.7 N・0.25 N·m は暫定（SAFETY_UNVERIFIED）。安全・合格の語は使わない。
> 数値の出典: **CAD_CONCEPT**（Fusion の体積・重心。密度は ASSUMED: PLA 1.24、TPU / スキッド 1.2、SG90 1.44（9 g 換算）、ToF 基板 1.45 g/cm³）。**Design の見積もり（Engineering 未検証）**。質量・重心の確定は Engineering。

## 1. 覆い A は首の襟と一体（1 回の印刷）にした

- Fusion `NECK-V v4 with COVER A (integral, one print)`: 首の背側 3 体（襟を持つ）に覆い A（y ±30 を各体の幅に分けて）を union。襟の前縁 φ 16° に 2° 重ねた。体積の増分は 759 mm³（覆い 843 − 重なり 84）。v3 は残した。**接着で付ける案より、重ねの面（約 100 mm²）が薄く弱いので、一体成形を推奨**。印刷の向き・支えの要否は未検査。

## 2. 頭 E3 統合版 v1 → v2 の質量・重心（Fusion の外形。中実の上限）

| | 質量 | 重心（x, y, z mm） |
|---|---|---|
| v1（頭の上・あごを中実 100%）| 355.1 g | (−201.0, 0.10, 40.8) |
| v2（同）| 362.4 g | (−201.2, 0.04, 40.2) |
| v1（頭の上・あごを 30% = 殻の仮定）| 256.2 g | (−201.6, 0.84, 46.3) |
| v2（同）| 261.7 g | (−201.3, 0.81, 45.5) |

- **絶対値は使えない**: 概念のあご・上の頭が中実で、`config/robot.yaml` の頭 約 90 g と桁が違う（殻の厚さ・内部部品は入っていない）。**v1 → v2 の差（+5〜7 g）と重心の移動（x 0.2〜0.7 mm、z −0.6〜−0.8 mm）だけが目安**。
- **SG90（約 9 g）が +y 側だけ**: 頭 90 g の予算で他が左右対称なら、重心の y は **約 +2.8 mm**（9 g × 27.7 mm ÷ 90 g）ずれる。**ロール（左右の傾き）の偏り**になり得る。**対策案（Design）**: (a) −y 側に同じ質量のダミー（ToF 基板・配線・おもり）を置く、(b) SG90 を中心線側へ（|y| 21.6 → 幅の制約でこれ以上寄せられない）、(c) 左右 2 個の SG90（部品増）。**訂正（ENTRY-E-0014）**: Engineering の許容は |y| ≤ 4 mm（マットの押し込み剛性 k ≥ 1 N/mm の仮定、ASSUMED）で、+2.8 mm は**許容内 = ダミー質量は不要**。上の (a)〜(c) は採らない（入れるなら 0 に近づけるだけ）。マットの k は HT-012 で測る。
- あごの掘り出し（v2）: 166,295 → 111,914 mm³（−54.4 cm³、−32.7%）。**殻の強度は未確認**。

## 3. Head Yaw との関係

Head Yaw は MVP の外（`CAD.md`: 5 サーボ = J1 Pitch + J2〜J5 Yaw）。覆い（首の襟、x −136〜−131）は Head Yaw の概念（J1 の 50 mm 前）と場所が重ならない。**MVP の範囲では干渉なし。Head Yaw を入れる時に再検査**。

## 4. 殻の仮定で出した質量・重心（R-013 / R-014、ENTRY-E-0012 (8)・E-0014 への回答）

出典: **CAD_CONCEPT**（Fusion の体積・表面積・重心。**殻の体積 ≈ 表面積 × 厚さで近似**。内部の補強・リブなし、穴の内面も表面積に含むので過大側）。密度 ASSUMED（PLA 1.24、TPU / スキッド 1.2、SG90 1.44、ToF 基板 1.45 g/cm³）。**Design の見積もり（Engineering 未検証）**。対象 = `HEAD E3 INTEGRATED v2`。体積 4 cm³ 超の 12 体（頭の上・あご・目・フードなど）を殻にし、残りは中実。

| 殻の厚さ | 質量 | 重心（x, y, z mm）|
|---|---|---|
| 1.2 mm | 137.3 g | (−199.7, 0.48, 38.0) |
| 1.6 mm | 169.2 g | (−200.3, 0.43, 38.0) |
| 2.0 mm | 198.6 g | (−200.6, 0.39, 38.3) |
| 2.5 mm | 233.5 g | (−200.8, 0.36, 38.6) |

- **概念の頭の質量は、殻にしても 137〜233 g で、`robot.yaml` の頭 約 90 g の 1.5〜2.6 倍**。原因の大きい体: あご 111.9 cm³（中実 138.8 g）、頭の上の左右 各 50.6 cm³（62.7 g）、フード（頭の上の visor）16.8 cm³（20.8 g）、目 各 9.2 cm³（11.4 g）。**質量の予算 90 g は、この形のままでは満たせない**（厚さ 1.2 mm・目を中空・あごの空洞化などの見直しが要る = Design の次の課題）。
- 重心 y は +0.36〜+0.48 mm（SG90 の 9 g を含む。**頭が重いので、SG90 の偏りは 約 2.8 mm でなく 0.4 mm 程度**）。重心 x は −200〜−201、z は 38。**J1 の軸（x −181.8、z 32.4）から x 方向に約 19 mm 前**（J1 の静的トルクは Engineering の計算）。
- **限界**: 殻の近似（表面積 × 厚さ）、中の部品（XIAO・サーボ・配線・電池なし）は含まない。実際の質量は Engineering の予算表と、殻の設計（Design）で決まる。

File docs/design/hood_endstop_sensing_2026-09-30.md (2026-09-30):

# フードの「下がりきった / 上がりきった」1 ビット（E-0013 (4)）と J1 サーボ箱の y 方向（E-0013 (5)）

> **先頭の注意**: KNUCKLE DRUM 後も、まっすぐ比で約 20 倍（18〜24 倍）のすき間が残る。背板は現行 CAD では未解決のまま。5.7 N・0.25 N·m は暫定（SAFETY_UNVERIFIED）。安全・合格の語は使わない。
> 数値の出典: 寸法 = **CAD_CONCEPT**、部品寸法・磁石・ホール素子 = **ASSUMED**（実物のデータシートで確認。購入は User の承認）。**Design の見積もり（Engineering 未検証）**。実機の確認 = HARDWARE_TODO HT-013（下）。Fusion `HOOD END-STOP SENSING STUDY 01 (E-0013 (4))`。

## 1. 要求（Engineering、E-0013 (4)）

SG90 級（アナログ）は電流・位置を返さないので、**フードが下がりきった 1 ビット**（と上がりきった 1 ビット）を機構側に持つ。**ゲートを閉じる合図はその 1 ビットが立った後**。昇降の指令から 0.6 s で上端 / 下端の 1 ビットが立たなければ、昇降を止めて保持・頭の前進を止めて記録する。

## 2. 3 案の比較

| | **案 H: ホール素子 + 磁石（推奨）** | 案 M: マイクロスイッチ | 案 S: スキッド接触 |
|---|---|---|---|
| 形 | フードの**後ろ壁の外面**（x −174.4）に φ3 × 1.5 の磁石。あごの中の**後ろ壁の背後**に基板（1.0 × 5 × 10）と**ホール素子 2 個**（下 z 8 / 上 z 12 = ストローク 4 mm）。素子は 3 × 2.9 × 1.1 級（SOT-23 相当、ASSUMED） | フードが下がりきった位置で後ろ壁（またはピン）が**スナップ式のマイクロスイッチ**（5.8 × 12.8 × 6.5 級）を押す | 足の帯が床に触れたら…（床が測れる = 較正の前提が崩れる） |
| 上端 / 下端の両方 | ○（素子 2 個） | 下端だけ（上端は別のスイッチ） | 下端だけ（間接） |
| 摩耗・ほこり | 非接触（磁石と素子の隙間 0.7 mm）。**ほこり・毛に強い** | 接点あり（摩耗・固着の恐れ） | 床の凹凸・マットで誤判定 |
| **挟み込み** | 指の入る隙間なし（あごの中）| スイッチの上の隙間 0 | — |
| 部品の増加 | 磁石 1 + 素子 2 + 基板（配線 4 本）| スイッチ 1〜2 + 配線 | なし |
| 主なリスク（prior / 未確認）| 磁石の温度・向き、SG90 の電源ノイズ、**磁石が他の磁気部品（コンパス・サーボの磁石）に影響**、素子の感度の選定 | スイッチの動作力（押し込み）、位置のばらつき ±0.3 mm | 崖・マットで信頼できない |
| 出典 | 全て ASSUMED（データシート未確認）| 同 | — |

**推奨は案 H**。理由: 非接触で摩耗が無く、上端・下端の両方を 1 個の磁石で取れ、指の挟み込み点を増やさない。**案 M はフォールバック**（Fusion に同じ場所へ重ねて置いた = どちらか一方を選ぶ）。案 S は較正の前提（足の帯の底が床に触れない）と衝突するので採らない。

## 3. 寸法（Fusion）

- 磁石: x −174.4〜−172.9、y 0、z 8（下）。フードが上がると z 12。
- ホール素子 下 / 上: x −172.2〜−169.3（磁石と 0.7 mm の隙間）、z 8 / 12。基板 x −169.3〜−168.3、y ±2.5、z 5.5〜14.5。
- あごのポケット（磁石の動き + 素子）: x −174.4〜−168.0、y ±3.5、z 5.5〜14.5（切っていない。工具体のみ）。**フードの後ろの dx 0.4 mm（平行リンクの後ろ向き）を含めても、隙間 0.3 mm 以上**。
- 判定: 下 = 「下がりきった」、上 = 「上がりきった」。**指令から 0.6 s でどちらも立たない → 停止 + 記録**（Engineering の判断。Design は 2 ビットを出すだけ）。

## 4. J1 サーボ箱の y 方向の寸法（E-0013 (5)）

- `CAD.md` の STS3215 の本体寸法（参照値・仮値。**実測なし**）**45.23 × 24.73 × 35 mm**。Design の REF 箱は **x 45（−190〜−145）× y 36（±18）× z 25（20〜45）**。→ **x = 45.23（長さ）、z = 24.73（縦）、y = 35 mm（幅）**の向き。REF の y ±18 = 36 mm は 35 mm に **約 0.5 mm ずつ丸めた余裕**（35 mm なら ±17.5）。**y に向けている寸法は 35 mm**。
- フードの外幅 ±16.6 は ±17.5 / ±18 のどちらの内側でも、干渉体積（s = 4 で 264 mm³）は同じ。実寸は実機が来てから（HT-011 の延長）。

## 5. 実機でしか分からないこと

**HT-013（P2）**: 磁石とホール素子の検出距離・ヒステリシス、SG90 の電源ノイズ下での誤動作、磁石の向き（極性）、実物の素子の寸法。手順は `ai-shared/HARDWARE_TODO.md`。

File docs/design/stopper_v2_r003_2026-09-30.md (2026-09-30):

# R-003 への回答 — ストッパー v2（窓 θ_E −4〜+3°、鋼ダウエル φ3 + TPU パッド）と ±4° の危険体積

> **先頭の注意**: KNUCKLE DRUM 後も、まっすぐ比で約 20 倍（18〜24 倍）のすき間が残る。背板は現行 CAD では未解決のまま。5.7 N・0.25 N·m は暫定（SAFETY_UNVERIFIED）。安全・合格の語は使わない。
> 数値の出典: 寸法・危険体積 = **CAD_CONCEPT / KINEMATIC_SIM**（Design の計算: 外形 STL、0.5 mm ボクセル、幅 5〜12.5 mm・深さ 8 mm 以上の届くすき間、範囲 x −250〜−110・|y| ≤ 60）。荷重・材質 = **Engineering の prior（ENTRY-E-0011）を引用**。**Design の見積もり（Engineering 未検証）**。実機の符号は **HT-001 の後**に窓を切る。
> **符号**: 姿勢ラベルは θ_E（+ = 頭を上げる）で書く。CAD の姿勢変換は θ_CAD = −θ_E（+ = 頭を下げる。`j1_sign_correction_2026-09-30.md`）。

## 0. 結論

1. **窓 θ_E −4〜+3° = CAD +4〜−3°**。窓（フードの尾、r 45.5〜48.5）は、**パッド t = 3 mm で φ 30.5〜48.5°（弧長 14.8 mm）**、**t = 6 mm で φ 26.9〜52.1°（20.8 mm）**、幅 3.6 mm、|y| = ±18。ピンは首の芯から半径方向に**鋼ダウエル φ3**（r 38〜48.5、埋め込み 7 + 露出 3.5）。
2. **危険体積（θ_E、Design の計算）**: **+4°（頭を上げる）= 151 mm³**、**−4°（頭を下げる）= 覆いなし 319 mm³ / 覆いあり 23 mm³（案 A）**。**Engineering の補間（+4° 164、−4° 覆いなし 205 / 覆いあり 13）とは、+4° は −8% で近く、−4° は覆いなしが +56%（205 → 319）、覆いありが +77%（13 → 23）で、補間は下側を過小に見ていた**。
3. **範囲 [−4, +3] の最悪**: 覆いなしは **−4° の 319 mm³**（覆いありは +3° の 44 mm³ で最悪 = 覆いなし / あり = **7.3 倍**。下側だけで見ると 319 / 23 = 14 倍。前回の「約 5 倍」は補間による過小）。

## 1. 危険体積の表（θ_E、mm³。0.5 mm、幅 5〜12.5・深さ 8 mm 以上。**計算した点 = 太字、補間なし**）

| θ_E | CAD | 覆いなし | 案 A（8° の殻）| 案 B（5° の短い殻）| 案 C（丸い襟巻き）| 出典 |
|---|---|---|---|---|---|---|
| −5°（範囲の外、参考）| +5 | 401 | 29 | 29 | 54 | `j1_cover_variants_eval`（CAD_CONCEPT）|
| **−4°（下げ側の端）** | +4 | **319** | **23** | **23** | **39** | 同上 |
| −3° | +3 | 105 | 6 | 6 | 8 | 同上 |
| −2° | +2 | 40 | 6 | 6 | 8 | 同上 |
| 0° | 0 | 2 | 2 | 2 | 2 | 同上 |
| +3° | −3 | 44 | 44 | 44 | 44 | 覆いは上側に効かない（`gap_pitch`）|
| **+4°（上げ側の端の手前）** | −4 | **151** | 151 | 151 | 151 | `j1_r003_eval.py`（p21）。覆いあり（A/B/C）でも 151 = 覆いは効かない |
| +5° | −5 | 601 | 601 | 601 | 601 | `gap_pitch_v3`（既存）|

- 上側（頭を上げる、下の後ろのくさび）は**覆いで変わらない**（前回のとおり形で埋まらない）。**+4° の 151 mm³ は +3°（44）の 3.4 倍、+5°（601）の 1/4**（補間 164 に近い）。
- **覆いと頭の重なり = 0 mm³**（全姿勢、案 A / C）。

## 2. 案 B

5° の短い殻（Fusion 590 mm³）。**範囲 −5° まで A と同じ値**（−4° = 23、−5° = 29）。詳細・見た目・User の判断は `j1_cover_variants_2026-09-30.md`。

## 3. 窓・ダウエル・パッドの寸法（Fusion `J1 STOPPER v2 + COVER VARIANTS STUDY 02 (R-003)`、STL `j1_cover_v2/`）

| 部品 | 寸法（mm、角は頭の座標） | 材質・由来 |
|---|---|---|
| **窓（フードの尾に切る）** | r 45.5〜48.5（貫通）、幅 3.6（|y| 16.2〜19.8 と −19.8〜−16.2）、**φ 30.51〜48.49°（t = 3）**。ピンの頭の座標での角 = φ_p + θ_E（φ_p = 40°）→ 動く範囲 **φ 36.0〜43.0°** | PLA のフード（壁 2 mm）を切る。**荷重で端面が壊れるかは未検査** |
| **鋼ダウエル φ3** | 長さ 10.5、半径方向 r 38.0〜48.5、φ_p = 40°、|y| = ±18。**首の芯に φ3.0 の穴（深さ 7、r 38〜45）へ圧入 + 接着**。露出 3.5（r 45〜48.5） | 鋼（Engineering の ASSUMED、約 147 N の曲げ）。**取り付けの強度は未検査** |
| **TPU パッド（両端）** | 弧長 3.0（t）× 幅 3.6 × 半径 2.0（r 46〜48）。窓の端面に接着 | **E-0011: 厚さ 3〜6 mm、E 3 MPa 級（柔らかい TPU、Shore 60A 前後 [ASSUMED]）。95A（E ≈ 26 MPa）では k が 9 倍になり衝撃が減らない**（材質の確認を Engineering に依頼） |
| ピンの穴（工具体）| φ3.0、r 38〜45、深さ 7 | 首の芯（NECK-V tongue core）に開ける工具体。今回は切っていない |
| 窓と覆い・襟の関係 | 窓 r 45.5〜48.5、覆い r 49.5〜51.1、襟 r 49+ | ダウエルの先端 r 48.5 と覆いの内面 r 49.5 の間 1.0 mm |

- **t = 6 mm の場合**: 窓 φ 26.86〜52.14°（弧長 20.8 mm）、パッド 6.0 × 3.6 × 2.0。**フードの壁（PLA 2 mm）の窓が長くなり、剛性が下がる**（未検査）。
- **窓の端の手前 2°（θ_E −2〜−4°、+1〜+3°）は ≤ 40 °/s**（Engineering、ソフト）。

## 4. 実機でしか分からないこと（HARDWARE_TODO に追記）

HT-008（TPU の硬さ・パッドのたわみ）、HT-009（ダウエルの圧入・窓の端面の支圧）、HT-001（符号）。詳細は `ai-shared/HARDWARE_TODO.md`。

## 5. 訂正と選択（ENTRY-E-0014 を受けて、2026-09-30 夜）

- **訂正**: 上の「TPU は E 3 MPa 級（Shore 60A 前後）が要る」は**誤り**。Design のパッド断面 3.6 × 2.0 = 7.2 mm² では E 3 MPa は底付きする（ひずみ 0.77 / 0.55 > 0.4）。**Engineering の 2 案から選ぶ**（どちらも鋼ダウエル φ3 が前提。120°/s・減速なしの SF p05）:
  - **P1**: 95A 級（E ≈ 20〜30 MPa）、厚さ 3 mm、窓 14.8 mm（φ 30.51〜48.49°）、SF 2.5〜2.9。**Design の既定 = P1**（窓の壁 2 mm の剛性を守る）。
  - **P2**: E ≈ 10 MPa 級（85A 前後、ASSUMED）、厚さ 4〜6 mm、窓 最大 20.8 mm（t = 6: φ 26.86〜52.14°）、SF 4.0〜4.6。衝撃を小さくしたい場合。
  - **選ぶ基準は HT-008 で測る E**（Shore ではない）。E が ±50% ずれても P1 / P2 の SF は上の範囲。
- **STL は t = 3 / t = 6 の両方を残した**: `j1_cover_v2/J1v2_WINDOW_V2_*.stl` + `J1v2_TPU_PAD_*`（t = 3）、`J1v2_WINDOW_T6_*` + `J1v2_PAD_T6_*`（t = 6）。Fusion `J1 STOPPER v2 + COVER VARIANTS STUDY 02` に両方。HT-008 の E を見て切り替える。**窓・穴はまだ切らない**（HT-001 の後）。
- **窓の端面の支圧**: 8〜12 MPa（PLA 圧縮 20〜30 MPa の仮定で SF 1.7〜3.6、83 N で余裕小。未検査 = HT-009）。**変形が出たら金属のスリーブ**（φ3 の黄銅パイプ等）を窓の端に入れる（Design の案。形は HT-009 の結果を見て起こす）。パッドは窓の端面へ**均一に接着**（片当たりは局所の応力が上がる）。ダウエルの圧入の引き抜き ≥ 約 120 N（Engineering の提案、HT-009）。

## 6. 範囲の外の危険体積（E-0012 (b)：+6〜+9°、−7.5°（覆いあり））

Design の計算（`tools/j1_cover_variants_eval.py`、`POSES` を環境変数で指定。0.5 mm、幅 5〜12.5・深さ 8 mm 以上。姿勢は y 軸まわりの回転（軸 (−181.8, z 32.4)）で作り、**+5°（601）・+10°（1562）の既存の値を同じ方法で再現して検証した**）。角度は θ_E。

| θ_E | 危険体積 mm³ | 覆い A の効き | Engineering の補間（E-0011）| 補間との差 |
|---|---|---|---|---|
| +3° | 44 | なし | 44 | 0 |
| +4° | 151 | なし | 164 | −8% |
| +5° | 601 | なし | 601 | 0 |
| **+6°** | **1270** | なし | 728 | **+74%** |
| **+7°** | **1432** | なし | 881 | +63% |
| **+8°** | **1584** | なし | 1066 | +49% |
| **+9°** | **1714** | なし | 1290 | +33% |
| +10° | 1562 | なし | 1562 | 0 |
| **−7.5°（覆いあり）** | **106**（覆いなし 1350）| あり | — | — |

- **+5° と +6° の間で 601 → 1270 に倍増**（下の後ろのくさびの幅が開く）。補間は **+6〜+9° を 33〜74% 過小**に見ていた。**+9° は +10° より大きい（1714 > 1562）**。「姿勢を残す案（+8° 以上）」の最悪は補間の 1066 でなく **+9° の 1714 mm³（+3° の 39 倍）**。
- **−7.5°（覆い A あり）= 106**（覆いなし 1350 = 12.7 倍）。**覆い A は範囲外の −7.5° まで効く**（−10° の 234 と合わせて）。
- 上側（θ_E +）は形で埋まらない（覆いは効かない）。**Engineering の範囲の結論 [−4, +3] は、この表でさらに強まる**（+3° → +5° の 13.7 倍の段は、+5° → +6° の 2.1 倍の段が続く）。

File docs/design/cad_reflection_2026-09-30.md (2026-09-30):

# CAD への反映（Fusion 復帰後の一括、2026-09-30 夜）

> **【先頭の注意】KNUCKLE DRUM 後も、まっすぐ比で約 20 倍（18〜24 倍）のすき間が残る。背板は現行 CAD では未解決のまま。5.7 N・0.25 N·m は暫定（SAFETY_UNVERIFIED）。安全・合格の語は使わない。**
> Fusion: `Serpens_DESIGN_SD01_BEAN_KNUCKLE_RECOVERY_20260929`（保存済み）。**既存のコンポーネント・ボディは変更していない**（追加した別コンポーネントだけ）。B2 の印刷結果を前提にしたフードの変更は入れていない。数値は CAD_CONCEPT。

## 追加した別コンポーネント（provenance はコンポーネント名・ボディ名に記載）

| コンポーネント | 中身 | 由来 | 状態 |
|---|---|---|---|
| `MOUTH FRONT LAYOUT STUDY 01` | 横のスキッド 2 本（x −226〜−178、\|y\| 36〜44、z 0〜10、前端 R6 で反らす、3,778 mm³ ×2）、後ろのスキッド 2 つ（x −172〜−164、\|y\| 14〜22、z 0〜7）、ToF 下向き（x −172〜−165、\|y\| ≤ 7、z 7〜9、空洞の外）、**斜め LED 2 個（3×3×3、横スキッドの前端 X −226、\|y\| 40、z 3〜6）** | `mouth_front_layout_2026-09-30.md` §2、User の指示（LED は Z ≤ 6） | 禁止域（\|y\| ≤ 34、口の面〜奥の壁の外、z ≤ 16.6）に入る部品 0（横のスキッドは足の帯 \|y\| 34 との間 2 mm）。既存の REF スキッド・顎板は手を付けていない（HEAD INTAKE の複製とは別） |
| `HOOD LIFT STUDY 01` | SG90 級（22.7×12.2×22.5、\|y\| 21.6〜33.8、x −213.8〜−191.1、z 10.2〜32.7）、取り付けの耳、ホーン + クランクピン（r 2.5 = 5 mm）、フード側のピンと耳（屋根の上の板、クランクピンが下から押す）、平行リンク（L 20、水平）左右 各 2 本 + ピン | `hood_lift_2026-09-30.md`（s = 5） | 概念。あごの掘り出し（+13.9 cm³）と J1 サーボ（要確認 792 mm³）は未反映（既存の体を切らない）。ケーブル・ばね・力の制限は未設計 |
| `J1 COVER + STOPPER STUDY 01` | 上の覆い（870 mm³）、ストッパーのピン ×2、窓の工具体 ×4（全範囲 / 変種 B） | `j1_cover_stopper_2026-09-30.md` | STL は `j1_cover/`。検査済み（覆いあり: −5° で 401 → 29）。下のくさびは形で解決できない |
| `PLATE VARIANT B concentric dome caps`（既存） | 背板 (b) の別コンポーネント | `plate_layer_2026-09-30.md` | **既に別コンポーネント**（現行 CAD は変更なし、J2〜J5 の p1: 1373 → 71 mm³）。User の外観の判断待ち |

## 未実施

- スキッド・ToF・LED を **HEAD INTAKE on E3 の頭本体・REF に組み込む**こと（既存の体の削除・移動が要る。User の許可待ち）。
- 頭の殻のあご側の掘り出し（フード + SG90 + リンク）。
- 上の 3 つのコンポーネントの重なりの数値検査（Fusion の干渉検査）。今回は STL と位置の計算のみ。

## 追加（User の許可「組み替えていい」「デフォルメ調でかわいく愛らしい感じ」）— `HEAD E3 INTEGRATED v1 - cute deformed`

- **User の許可を受けて、既存の頭本体・REF を組み替えた形の統合版を別コンポーネントで作った**（元の `HEAD E2-V VISOR`・`MOUTH LINE`・`LIGHT+SKID`・`CHIN SHIELD`・`HEAD INTAKE on E3 STUDY`・REF は**消していない**。統合版は複製から作り、元は非表示/そのまま）。
- 中身（63 ボディ）: E2-V の頭（目・鼻・眉・口の線・通常光のスリット）の複製、**フード B2 の形**（壁・屋根・足の帯）と TPU 垂れ布のゲート、フード昇降（SG90 級・クランク・リンク）、横のスキッド・後ろのスキッド・ToF の窓・頬のレンズ。**旧 REF の頭のスキッド・双子スキッド・顎板・頬の下の LED は入れていない**（口の前の禁止域から外した）。
- **あご（実体）の掘り出し**: 166,295 → 109,844 mm³（**−56.5 cm³、−34 %**）。内訳の目安: フード + 5 mm 昇降の包絡 約 45 cm³、SG90 の穴 7.1、リンクの溝 4.2、クランクの範囲 0.9、ToF の窓 1.1。**頭の殻の強度は Engineering の確認が要る**（あごが中実か殻かも未確認）。
- **デフォルメ調のかわいい仕上げ（Design の見立て、User の好み）**: 目は大きな黒い目に白いハイライト、頭はセージ色、あごはアイボリー、フードはクリーム色、**横のスキッドは上から見て丸いスタジアム形（つま先が反る R6）でミントの色**、後ろのスキッドは丸いかかと（半球）、**頬の LED は直径 4 のピンクの丸いレンズ**（横スキッドの前端、Z 4.5）、TPU の垂れ布もピンク。図: `assets/head_e3_integrated_v1_iso_a.png`、`_iso_b.png`、`_front.png`。
- **限界**: 質感・色は Fusion の見た目のみ（印刷・実物の材料ではない）。統合版の頭のあごの中の SG90 の配線・ばね・ゲートの取り付けは未設計。ピンクの LED レンズが実際に光る配光・拡散は未検証（HG-H2 の値は点光源の合成視覚）。**J1 の覆い（上の輪の殻）と背板 (b) のかわいい形（丸い縁・スカラップ）は次**。

## 追加（2026-09-30 夜、自律運用・R-003 / R-005 / R-007）

- **先頭の注意**: KNUCKLE DRUM 後も、まっすぐ比で約 20 倍（18〜24 倍）のすき間が残る。背板は現行 CAD では未解決のまま。5.7 N・0.25 N·m は暫定（SAFETY_UNVERIFIED）。安全・合格の語は使わない。
- 別コンポーネントを追加（元は未変更、保存済み）: `J1 STOPPER v2 + COVER VARIANTS STUDY 02 (R-003)`（窓 v2・鋼ダウエル・TPU パッド・覆い A/B/C、`stopper_v2_r003_2026-09-30.md`）、`TOF BOARD PLACEMENT STUDY 01 (R-007)`（S1 / S2、`tof_board_placement_2026-09-30.md`）、`HOOD LIFT STUDY 02`（s = 4、TPU 板ばね耳、`hood_lift_options_2026-09-30.md`）、**`HEAD E3 INTEGRATED v2`**（v1 + ToF 基板入りの肉球 + s = 4 + あごの再掘り。あご 166,295 → 111,914 mm³、−32.7%）。v1 と元は非表示。
- **窓・ダウエル穴は首の芯・フードに切っていない**（HT-001 = 実機の符号の後）。工具体だけ。

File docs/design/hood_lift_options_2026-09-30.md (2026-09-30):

# フード昇降のコンセプト 3 案（挟み込みの観点で比較）— 2026-09-30

> **先頭の注意**: KNUCKLE DRUM 後も、まっすぐ比で約 20 倍（18〜24 倍）のすき間が残る。背板は現行 CAD では未解決のまま。5.7 N・0.25 N·m は暫定（SAFETY_UNVERIFIED）。安全・合格の語は使わない。
> 数値の出典: **CAD_CONCEPT**（干渉体積 = `tools/hood_lift_check.py`、STL・0.5 mm ボクセル）、**prior / ASSUMED**（SG90 の停動 0.12 N·m、TPU 95A の E = 26 MPa、フードの質量 11.4 g）、**Engineering の枠組み PROVISIONAL**（ENTRY-E-0008 (6): 上げる側 ≤ 2.8 N、自重降下、上げたときの下のすき間 ≤ 4 mm、縁の幅 ≥ 0.8 mm か 速さ ≤ 10 mm/s）。**Design の見積もり（Engineering 未検証）**。実測は HARDWARE_TODO HT-006 / HT-008 / HT-010。

## 0. 前回（D-0009）からの変更

- **ストロークは 4 mm に下げた**（Engineering: 上げたときの下のすき間 ≤ 4 mm。5 mm は境界で不可、8・10 mm は 5〜25 mm の帯）。s = 4 の干渉（`results/hood_lift_2026-09-30.json`）: あご +11.2 cm³（s = 5 は +13.9）、屋根の上面 z 20.6、**カメラ XIAO と 1.4 mm の余裕（干渉 0）**、**J1 サーボの REF 箱と 264 mm³**（s = 5 は 792）。
- **上げる側の力の制限が要る**（SG90 のクランクは停動 60 N（r = 2 mm）で許容 2.8 N の 21 倍）。3 案とも「サーボと フードのあいだに**力を制限する弾性要素**を直列に入れる」。**下げる側はサーボが押さない**（フードが自重でクランク/ひもに載って降りる = 力は自重 0.112 N だけ）。
- **J1 は使わない**（窓 −2〜+1° のまま）。

## 1. 3 案

| | 案 L1: コイルばね直列 | **案 L2: TPU の板ばね耳（推奨）** | 案 L3: ひも巻き取り + 直動ガイド |
|---|---|---|---|
| 形 | SG90 のクランク（r 2）→ **圧縮コイルばね入りのカップリング**（予圧 0.6 N、k 0.3 N/mm）→ フードの耳。平行リンク L 20 | SG90 のクランクピンが、フードの**TPU の板ばねの耳**（幅 12 × 厚さ 1.4 × 長さ 9）を**下から押す**。平行リンク L 20 | SG90 のドラム（r 3）に細い**ナイロンのひも**、途中に**TPU のバンド**（弾性要素）→ フードの耳。**φ3 の直動ガイドピン 2 本**（後ろの角）。リンク無し |
| **上げる側の最大の力（出典: 計算 + prior）** | 予圧 0.6 + 0.3 × 4 = **1.8 N**（ばね定数 ±20% で 1.4〜2.2 N） | k = 3EI/L³ = **0.29 N/mm × 4 mm = 1.2 N**（E ±30% で 0.8〜1.5 N）。**曲げの応力 2.7 MPa（弾性域の見込み）** | バンド k 0.4 N/mm × 4 mm = **1.6 N**（E ±30% で 1.1〜2.1 N） |
| 上げる側の力 ≤ 2.8 N（E-0008） | ○（余裕 1.3〜2.0 倍） | **○（余裕 1.9〜3.5 倍）** | ○（余裕 1.3〜2.5 倍） |
| **下げる側の力** | 自重 0.112 N（クランクが降りる速さで降りる） | 自重 0.112 N + 板ばねのたわみ（**0.38 mm 沈む**だけ。力は増えない） | 自重 0.112 N（ひもが緩む速さ。ガイドの摩擦が抵抗） |
| 降下の速さ（サーボが決める） | 10〜20 mm/s（クランク 0.2〜0.4 s） | 同じ | 同じ（ドラムの速さ） |
| **指を挟む所（すき間 5〜25 mm の帯に入る所）** | 上げたときの壁の下 = 4 mm（≤ 4 OK）。フードの外側と あごの溝 = 0.3〜0.5 mm。リンク板と溝 = 各 1.2 mm。**5〜25 mm の帯は 0 か所** | 同じ。**耳の板ばねの下（クランクとの間）は あごの内側で指が入らない**。**5〜25 mm の帯は 0 か所** | 壁の下 4 mm、ガイドピンと穴 0.2 mm。**ひもが指に巻く恐れは無い**（あごの内側）。**5〜25 mm の帯は 0 か所** |
| 部品数 | 多い（ばね・カップリング・リンク・ピン） | **少ない**（耳が板ばね兼用。リンク + ピン） | 中（ドラム・ひも・バンド・ガイド 2 本。リンク無し） |
| 前後のずれ dx（c への影響） | 0.4 mm（L = 20、s = 4） | 0.4 mm | **0**（直動） |
| 主なリスク（prior / 未確認） | ばねの座屈・予圧のばらつき | **TPU の E・クリープ（吊り上げたまま長時間で沈む）、板ばねの疲労** | ひもの伸び・ドラムの巻き乱れ、ガイドの固着（ほこり） |
| 見た目 | 部品が多い（頭の中） | **すっきり**（耳の板ばねだけ、ピンク色にできる） | ひもが見える恐れ |
| 未検証・実測 | ばねの予圧の実測 | **板ばねの力（はかり）、E の実測、クリープ = HT-008** | ひもの伸び・ガイドの固着 |

## 2. 共通の挟み込みの確認（案によらない）

- 縁: 壁の下端は **R0.8 の丸め**（前回のまま）+ **足の帯の幅 3.6**（自重 0.112 N を約 36 mm² で受けて 約 3 kPa。幅 0.8 mm でも 14 kPa、0.4 mm で 28 kPa = 縁が細いほど上がる）。**縁 ≥ 0.8 mm の条件は満たす**。
- 上げる側が指を押す場合: 3 案とも **上げる力 ≤ 1.8 N（prior）**。指が壁の下（4 mm のすき間）に入る前に、口の周りへ手を入れない（表示は Engineering / User）。**指の許容力は Engineering が決める**。
- 自重降下（サーボが押さない）を維持するため、**降ろす動作は必ず「クランク（ひも）を緩める向き」**にする。**フードがガイドで固着すると、降りない**（安全側: 上がったまま止まる）。降りたまま上がらない（板ばねが受け持つ上げる力 1.2 N を超える摩擦）場合は、位置指令の電流で検出する（Engineering）。

## 3. 推奨と理由

**案 L2（TPU の板ばね耳）**。理由: (1) 上げる側の力が最も小さく（1.2 N、許容の 2.8 N の 43%）、(2) 部品が少なく、(3) 力の制限がそのまま耳の形で決まり（幅・厚さ・長さを変えて調整）、(4) 見た目もすっきり。**弱点は TPU の E とクリープが prior**（HT-008 で実測。E が 2 倍なら力も 2 倍 = 2.4 N でまだ ≤ 2.8 N）。**判断は Engineering の枠組みの範囲内**なので、User に聞かない。

## 4. できていないこと

- CAD は `HOOD LIFT STUDY 01`（コンセプト形状のまま。クランク r 2.5、s = 5 の寸法）。**s = 4・板ばねの耳に直すのは次の CAD 更新**（板ばね耳 = 幅 12 × 厚さ 1.4 × 長さ 9 の TPU、クランク r 2）。
- 力の制限（TPU の板ばね）の実測、クリープ、疲労は未確認（HARDWARE_TODO HT-008）。

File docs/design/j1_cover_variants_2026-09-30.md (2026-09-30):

# 上の輪の覆い（襟の前縁の延長）— 3 案の比較（R-003 ③ / R-011）

> **先頭の注意**: KNUCKLE DRUM 後も、まっすぐ比で約 20 倍（18〜24 倍）のすき間が残る。背板は現行 CAD では未解決のまま。5.7 N・0.25 N·m は暫定（SAFETY_UNVERIFIED）。安全・合格の語は使わない。
> 数値の出典: **CAD_CONCEPT / KINEMATIC_SIM**（Design の計算: 外形 STL、0.5 mm ボクセル、幅 5〜12.5 mm・深さ 8 mm 以上の届くすき間。`tools/j1_cover_variants_eval.py`、結果 `results/j1_cover_variants_*.json`）。**Design の見積もり（Engineering 未検証）**。角度は θ_E（+ = 頭を上げる。CAD の姿勢 = −θ_E）。
> 図: `ai-shared/assets/j1_cover_variants_2026-09-30.png`（θ_E −4° の断面。橙 = 頭、緑 = 首、ピンク = 覆い、青 = 危険なすき間）。STL `j1_cover_v2/`、Fusion `J1 STOPPER v2 + COVER VARIANTS STUDY 02 (R-003)`。

## 0. 結論

1. **どの案でも、θ_E −4°（下げ側の端）で危険体積は 319 mm³ → 23〜39 mm³**。上側（+3° = 44、+4° = 151）は覆いで変わらない。
2. **範囲 [−4, +3] の最悪**: 覆いなし **319（−4°）**、案 A / B / C は **44（+3°）**（−4° の 23〜39 より大きい）→ **覆いあり / なし = 7.3 倍**（ENTRY-E-0011 の「約 5 倍」は補間による過小。**Design の計算で −4° が 205 でなく 319**）。
3. **推奨（安全側）は案 A**（8° の殻）。案 B（5°）も範囲内（−5° まで）では同じ値（23 / 29）だが、**A は範囲を超えて（−10° で 234）効く**ので、ストッパーが効かなかった場合の余裕になる。**見た目を優先するなら B**（伸びが 7.1 → 4.5 mm）。

## 1. 比較表（θ_E、危険体積 mm³。計算した点のみ）

| θ_E | 覆いなし | **案 A**（8°、843 mm³）| **案 B**（5°、590 mm³）| **案 C**（丸い襟巻き、1037 mm³）|
|---|---|---|---|---|
| −5°（範囲の外）| 401 | 29 | 29 | 54 |
| **−4°** | **319** | **23** | **23** | **39** |
| −3° | 105 | 6 | 6 | 8 |
| −2° | 40 | 6 | 6 | 8 |
| 0° | 2 | 2 | 2 | 2 |
| **+4°（上側。覆いは効かない）** | 151 | 151 | 151 | 151 |
| **範囲 [−4, +3] の最悪** | **319** | **44**（+3°）| **44** | **44** |
| 覆いと頭の重なり mm³（全姿勢）| — | 0.0 | 0.0 | 0.0 |
| PLA の質量（目安、1.24 g/cm³）| — | 1.0 g | 0.7 g | 1.3 g |

（θ_E −6° 以下の範囲の外は、案 A の −10°（= 234、D-0010）以外は計算していない。A は範囲を超えて効くという記述は、−10° の 234 の 1 点だけの根拠。結果ファイル `results/j1_cover_variants_{A,B,C}_2026-09-30.json`。Fusion の体積は A 843 / B 590 / C 1037 mm³、ボクセルの体積は 870 / 600 / 1054。）

## 2. 案の形と見た目（User の判断）

| | 形 | 見え方 |
|---|---|---|
| **A** | 襟の前縁から**同心の薄い殻**を 8° 前へ（フードの上、r 49.5〜51.1、厚さ 1.6、|y| ≤ 30）。前へ約 7.1 mm | 襟が少し前へ伸びる。**すっきり**。角は直線 |
| **B** | 同じ形を **5°**（前へ約 4.5 mm）| A よりさらに控えめ |
| **C** | 短い殻（3°）+ 先に **φ4 の丸い巻き（襟巻き / スカーフ）**、両端が丸い球 | **ぽってり丸い縁。デフォルメ調に合う**。ただし効きは A・B より弱い（−4° で 39、−5° で 54）|

## 3. 確認したこと（覆いが他の機能を妨げないか）

- **取り込みの隙間（口の下の c）**: 覆いは首の襟（x −136〜−131）にあり、口の面（x −236）から 100 mm 後ろ。**足の帯・フードに触れない**（重なり 0）。J1 の窓 −2〜+1° の中で、頭・フードと 0 mm³。
- **ToF の視界**: ToF（横スキッド前端 x −224〜−208、z 3〜6）と覆い（z 44〜53）は 70 mm 以上離れ、視野 27° の円錐（下向き）に入らない。
- **斜め LED の光**: LED（x −226〜−228、|y| 40、z 3〜6）から前の床（x −300〜−250）への光線は、覆い（x −136 より後ろ）に遮られない。
- **口の前縁**: 覆いは 100 mm 後ろ。干渉なし。
- **カメラ（x −232〜−217、z 22〜38）の視野**: 覆いはカメラの面より後ろ。入らない。
- **未確認**: 印刷の反り・襟の公差での擦れ（HT-010）。頭ヨー（Head Yaw）の回転は入っていない（次）。

## 4. User に聞く 1 点（見た目）

**上の輪の覆い（襟が前へ 5〜7 mm 伸びる薄い殻）を採るか。** 案 A（推奨・安全側）/ 案 B（控えめ）/ 案 C（丸い襟巻き）/ なし。**なしの場合、下側 −4° は 23 → 319 mm³（約 14 倍）、範囲の最悪は 44 → 319（7.3 倍）**。

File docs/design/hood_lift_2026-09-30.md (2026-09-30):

# フード昇降（cloche drop）の概念 — 2026-09-30 夜

> **【先頭の注意】KNUCKLE DRUM 後も、まっすぐ比で約 20 倍（18〜24 倍）のすき間が残る。背板は現行 CAD では未解決のまま。5.7 N・0.25 N·m は暫定（SAFETY_UNVERIFIED）。安全・合格の語は使わない。**
> 数値は CAD_CONCEPT / KINEMATIC_SIM（STL・ボクセル、Fusion なし）。**Design の見積もり（Engineering 未検証）**。B2 の印刷結果を待たない作業で、B2 の結果を前提にしたフードの形の変更は入れていない。

## 0. 3 行

1. **ストローク 5 mm までなら現行の頭 E3 に入る**（あごを +13.9 cm³ 追加で掘る。J1 サーボの箱と 0.79 cm³ 衝突）。**8・10 mm はカメラ（+0.8 / +1.4 cm³）と J1 サーボ（+2.6 / +4.0 cm³）に当たり、あごも +22.2 / +27.3 cm³ 掘る** → 頭の中身を動かす設計が要る。
2. 駆動は SG90 級 1 個（頭の横、|y| 21.6〜33.8）＋ **平行リンク（長さ 20、ほぼ水平）** ＋ **上向きだけ押すクランク**。**下げる力はフードの自重（0.11 N）だけ**にして、サーボの力を指に掛けない。**J1 は使わない**（窓 −1〜+1° のまま）。
3. 上げたときの下のすき間が 5 mm 以下なら「5 mm 未満」の指の規則を満たす。**8・10 mm は 5〜25 mm の帯に入る**（縁を丸める・TPU の縁・力を小さくするが要る）。挟む力の上限は **Engineering への依頼**（下）。

## 1. 使い方と寸法（[B] 依頼、[A] 仮定、[C] 計算）

- 普段はフード（口）の下端が床から **3〜5 mm 上**（[B]）。物の上へ**落とす**（cloche）。ストロークは **5 / 8 / 10 mm**（[B]）。B2 と同じフード（口 60→30 / 30、空間 30×30×15、壁 1.6、屋根 1.6）。
- 「床から 3〜5 mm 上げる」に必要なストロークは **3〜5 mm**。8・10 mm は物（ビーズ φ8・立方体 10 mm）を**下からくぐらせる**用途でしか要らない（Design の見立て）。
- J1 で同じ高さを出すと、口の前縁が 0.95 mm/° なので **5 mm = 5.3°**（窓 −1〜+1° の外。ピッチの危険なすき間 p8 = 2087 mm³ の側）。**フード昇降ならこの範囲を使わない**（J1 の窓は 12 ステップ = 1.06° のまま）。

## 2. 頭 E3 との干渉（mm³、`tools/hood_lift_check.py`、0.5 mm ボクセル、L = 20 の平行リンクで後ろへ dx 0.6〜2.7 を含む掃引）

前提: 頭の外形 = `HEADV__*`（p0）、Engineering の REF 箱 = `concept_geometry.SENSORS` ＋ J1 サーボの箱（x −190〜−145、z 20〜45、y ±18 = Fusion の REF 箱。**当初 ±22.6 と仮定して計算したが、±18 に直して再計算しても同じ数**）。フードが**床の位置（s = 0）から s の高さまで動く掃引の全域**で見る。

| ストローク s | 屋根の上面 z | あごを**追加で**掘る（s = 0 に対して） | カメラ XIAO | IR LED | J1 サーボ（REF 箱 y ±18） | 平行リンクの後ろ向きのずれ dx |
|---|---|---|---|---|---|---|
| 0（現行 E3） | 16.6 | 0（基準。頭の実体との重なり 31.1 cm³） | 0 | 0 | 0 | 0 |
| 3 | 19.6 | **+8.4 cm³** | 0 | 0 | 0 | 0.23 |
| **5** | 21.6 | **+13.9 cm³** | 0（**0.4 mm の余裕**） | 0 | **792** | 0.64 |
| 8 | 24.6 | +22.2 cm³ | **788** | 0 | **2,599** | 1.67 |
| 10 | 26.6 | +27.3 cm³ | **1,418** | 36 | **3,968** | 2.68 |

- s = 0 のときの REF との重なり（ToF 下向き 648、斜め LED 140×2、頭のスキッド 5,379）は E3 の報告どおりで、**移設済みの配置（`mouth_front_layout`）で解消する分**。上の表には入れていない。
- あごの追加の掘りは **s = 5 で 13.9 cm³**。もとの空洞（25.0 cm³）の 1.5 倍近く。**頭の殻の強度は Engineering の E-0006 (b) の確認が要る**（未検証）。**s = 8・10 は掘る量が多く、現実的でない**（Design の見立て）。
- **s = 5 の J1 サーボとの衝突 792 mm³**: 屋根の後ろ端（x −190〜−176、z 20〜21.6）。J1 の軸は動かせない（x −181.8）ので、(i) 屋根の後ろの 14 mm だけ低く（15 mm の空間の高さを守るなら不可）、(ii) ~~サーボの幅が狭ければ解消~~ → **Fusion の REF 箱は y ±18 で、フードの幅（±16.6）はその内側 → 幅では解消しない**（±18 で再計算しても 792 のまま）、(iii) ストロークを 4 mm 以下にする、のどれか。**未決**。
- SG90（22.5×12.2×22.7 mm、6.2 cm³）を置ける位置（あごの実体の中で、REF・s = 5 と 8 のフードの掃引から 1 mm 以上離れる）: **x −213.8〜−191.1、|y| 21.6〜33.8、z 10〜33**（あごの外面まで 3〜15 mm。z 10 で最も薄い 3 mm）。**左右どちらか 1 個**。ケーブルと耳（フード側のピン）は未設計。

## 3. 機構（概念）

- **平行リンク**: フードの両側の壁（|y| 16.6〜18.6、局所 x 34 付近）に φ2 ピン、あごの側に 20 mm 離れた ピボット。リンクは下げた状態でほぼ水平（L = 20）、上げると φ = 14.5° / 23.6° / 30°（s = 5 / 8 / 10）。**上下と同時に後ろへ 0.6 / 1.7 / 2.7 mm ずれる**（前後の位置は口の面が動くので、**c と口の位置には影響**。リニアガイドなら 0）。
- **リニアの案**: φ3 のガイドピン 2 本（フードの後ろの角、|y| 19）＋スライド。dx = 0。部品点数は増えるが、口の位置が動かない。**どちらを採るかは未決**（B2 の結果に依存しない）。
- **駆動**: SG90 級 1 個。ホーン半径 r = s/2 = **2.5 / 4 / 5 mm** のクランクで、クランクピンが**フードの下の受けを上へ押す**（上向きだけ。下は**フードが自重で受けの上に載って降りる**）。フードは**サーボの速さで降りる**（自由落下ではない）。反対側は駆動なしの平行リンク（ねじれは未確認）。
- **仮定した力と速度 [A]**（SG90 の停動トルク 0.12 N·m @4.8 V を仮置き）:

| s | クランクピンの最大の力（0.12 N·m ÷ r） | フードの自重 | 昇降の速さ（0.5 s） | 自由落下したときの速さ / エネルギー（**故障したとき**の上限） |
|---|---|---|---|---|
| 5 | 48 N | 0.112 N | 10 mm/s | 0.31 m/s / 0.56 mJ |
| 8 | 30 N | 0.112 N | 16 mm/s | 0.40 m/s / 0.89 mJ |
| 10 | 24 N | 0.112 N | 20 mm/s | 0.44 m/s / 1.1 mJ |

- **クランクを上向きだけ押す形にすると、下向きにフードが指へ掛ける力は自重 0.11 N（サーボ由来の力が掛からない）**。指が下にあってサーボが降りきっても、フードは指に載るだけでクランクピンだけが離れる。**上向きの力（最大 24〜48 N）は指を挟まない側の力**（上げるときに指が壁の内側に入っていなければ）。**その値そのものが大きすぎるので、サーボの力を制限する方法（電流・ホーン側のばね）は未設計**。
- 質量 [A]: フード 11.4 g（PLA）＋ SG90 9 g ＋ リンク・ピン・ばね 約 3 g = **約 23 g**（あごの掘り出し分 −18〜−31 g は殻の中実／中空の確認待ち）。

## 4. 指を挟まない形

- 上げたときの壁の下と床のすき間は **s**。**s ≤ 5 mm は「5 mm 未満」を満たす**（ぎりぎり）。s = 8・10 は **5〜25 mm の帯**（指の先が入る）。
- 壁の下端（厚さ 1.6）は**全面を R0.8 で丸める**（E-0007 (5): 縁の圧力。0.4 mm の縁を丸める）。足の帯（幅 3.6）の下面は平らのまま（c と平らさの基準）。**下端に TPU の縁（幅 3.6、厚さ 0.8、ショア 95A 級 [A]）を貼る案**: 自重 0.11 N を 幅 3.6 × 指の接触長 10 mm ≒ 36 mm² で受け、**約 3 kPa**（縁だけの丸め（16 mm²）は 約 7 kPa）。
- **挟む力の上限は Design が決めない**。**Engineering への依頼**: (1) 自重 0.11 N ＋ ばね力の上限（何 N まで許容するか）、(2) 上げ・下げの速さの上限（上の 10〜20 mm/s でよいか）、(3) 5〜25 mm の帯を通る s = 8・10 を採るかの判断、(4) 指の挟み込みの確認方法（Engineering の試験計画）。
- 口の下端が床に当たる音・跳ね返りの評価は未実施。

## 5. できていないこと

- **CAD は概念の形だけ作った**（Fusion 復帰後。別コンポーネント `HOOD LIFT STUDY 01`、s = 5、`tools/fusion_hood_lift.py`、`cad_reflection_2026-09-30.md`）: SG90 級・クランク・耳・平行リンク・ピン。**あごの掘り出し、SG90 の穴、ばね、ケーブルは未反映**（既存のフードと頭は変更しない）。SG90 は軸を x 方向（前面）にして、\|y\| 21.6〜33.8 に収めた（軸を y 方向にすると厚み 22.7 が \|y\| に出て、あごの外へ出る）。
- 頭の殻の強度、ケーブル、サーボの力の制限、反対側のねじれ、リンクの長さの最適化（L = 20 は仮）、リニア案の比較。
- 数値の再現: `python docs/design/tools/hood_lift_check.py`（結果 `results/hood_lift_2026-09-30.json`。頭の STL は scratch `C:\Users\Public\serpens_gapcheck\local3`）。

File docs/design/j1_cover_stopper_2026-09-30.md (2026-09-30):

# J1 の箱形カバーとストッパー — 形・STL・検査（2026-09-30 夜）

> **【先頭の注意】KNUCKLE DRUM 後も、まっすぐ比で約 20 倍（18〜24 倍）のすき間が残る。背板は現行 CAD では未解決のまま。5.7 N・0.25 N·m は暫定（SAFETY_UNVERIFIED）。安全・合格の語は使わない。**
> 数値は CAD_CONCEPT / KINEMATIC_SIM（外形 STL、0.5 mm ボクセル、内部部品・公差・たわみなし）。**Design の見積もり（Engineering 未検証）**。**姿勢の符号は `j1_sign_correction_2026-09-30.md` を先に読む（CAD の符号は + が頭を下げる。Engineering の θ_E = −θ_CAD）。**

Fusion: `J1 COVER + STOPPER STUDY 01`（別コンポーネント。既存の首・頭は変更していない）。STL: `j1_cover/`。作り方: `tools/fusion_j1_cover_stopper.py`。検査: `tools/j1_cover_eval.py`、`tools/j1_cover_eval_run.py`、結果 `results/j1_cover_eval_2026-09-30.json`、`results/j1_filler_voxel_2026-09-30.json`。

## 0. 結論（3 行）

1. **上の輪の覆い（襟の前縁を同心の殻で 8° 前へ延ばす、r 49.5〜51.1、厚さ 1.6、|y| ≤ 30、870 mm³）は、頭を下げる側のすき間を大きく減らす**: **Engineering の −5°（範囲の端 = CAD +5°）で 401 → 29 mm³、CAD +10°（範囲外）で 2062 → 234 mm³**。全姿勢で頭との重なり 0。
2. **下の後ろのくさび（頭を上げる側）は、首側の詰め物でも頭側の詰め物でも埋まらない**（頭がその領域を他の姿勢で通るため）。**Engineering の +5° = 601（詰め物で 417〜419）、+10° = 1562（詰め物で 1551）のまま**。形で解決できない → **範囲を狭める（+3° = 44 mm³）か、覆いを動く部品にする**の判断が要る。
3. **ストッパー**は、首の芯から半径方向に出るピン（φ3、|y| 18）と、フード（r 46〜48）に切る弧状の窓（工具体）。窓は 2 種: **全範囲（Engineering −5〜+10°）**と **変種 B（−5〜+3°、下のくさびで制限）**。**荷重の受け方・強度は未検査**。

## 1. 検査の結果（危険体積 mm³、幅 5〜12.5 mm・深さ 8 mm 以上の届くすき間、範囲 x −250〜−110、|y| ≤ 60）

| Engineering の θ_E（+ = 頭を上げる） | CAD のラベル | 覆いなし | 上の覆いあり | 首側の詰め物（ボクセル、上限の試験） | 頭側の詰め物 | 両方 |
|---|---|---|---|---|---|---|
| −10°（範囲外） | +10 | 2062 | **234** | 6 | 2 | 0 |
| **−5°（範囲の端）** | +5 | 401 | **29** | 0 | 21 | 0 |
| −3° | +3 | 105 | 6 | — | — | — |
| −2° | +2 | 40 | 6 | 1 | 13 | 1 |
| −1 / 0° | +1 / 0 | 3 / 2 | 3 / 2 | — / 0 | — / 8 | — |
| +3° | −3 | 44 | — | 1 | 46 | 1 |
| **+5°（範囲の端の手前）** | −5 | 601 | 601 | 417 | 603 | 419 |
| **+10°（範囲の端）** | −10 | 1562 | — | 1551 | 1562 | 1551 |

- 「上の覆い」は Fusion で作った実際の殻（STL）。**「詰め物（ボクセル）」は、全姿勢の頭の掃引と衝突しない領域だけを 0.5 mm のブロックで埋めた上限の試験**（形の案ではない。首側の詰め物 3,000 mm³ 弱、頭側 3,900 mm³ 弱）。殻で残る 234 / 29 は、殻が 8° 分しか届かないため（首側の詰め物ならほぼ 0）。
- **下のくさびが埋まらない理由**: 頭の掃引（−10〜+10°）が、すき間の領域を通る。首側に何を置いても、別の姿勢で頭に当たる。頭側に置いても首に当たる（詰め物の候補の残りが 3,900 mm³ あっても、すき間の体積は減らない）。
- 覆いと頭との重なり: p8・p16・p15・p14・p0・p13・p7 すべて 0.0 mm³。

## 2. 形（Fusion の別コンポーネント）

- **COVER UPPER**: 首の J1 軸 (−181.8, z 32.35) まわりの殻。r 49.5〜51.1、角 φ 14〜24°（襟の前縁 φ 16° を 2° 重ね、+8° 前）、|y| ≤ 30（穴の全幅 ±30）。x −136.6〜−132.2、z 44.3〜53.1、870 mm³。フード（r 46〜48）との隙間 1.5 mm。**首の襟に固定する接合は未設計**（襟の前縁に重ねて接着 / 一体成形のどちらでもよい）。
- **STOP PIN**（2 本）: 首の芯（r 45）の側面、|y| = ±18、φ 40°、半径方向 r 44〜48.5、φ3。
- **STOP SLOT WINDOW**（工具体、フードの尾に切る）: φ 33.2〜51.8°（全範囲: Engineering −5〜+10°）と φ 33.2〜44.8°（**変種 B: −5〜+3°**）、r 45.5〜48.5、幅 3.6。角の作り方: ピンは首に固定、窓は頭に固定 → 頭の座標でのピンの角 = φp − θ_CAD。範囲の両端 + ピンの半角 1.8° を窓の端にした。
- **未検査**: ピンの根元の固定（首の芯 PLA/金属）、窓の端面の荷重（フード 2 mm の PLA が受けるか）、フードの曲げ、窓のバリ・磨耗。**J1 のトルク上限（0.449 N·m の既定）でストッパーに当たったときの力は Engineering の計算**（トルク ÷ 腕 36〜47 mm ≒ 10 N 級）。

## 3. 人・Engineering が決めること

- **Engineering**: 範囲の端の正しい向き（θ_E の符号）と、+側（頭を上げる）を **+3° に狭めてよいか**（下のくさび 44 mm³）。狭めないなら、**+5° = 601 / +10° = 1562 mm³ が残る**（動く覆いでない限り形で減らせない）。
- **User**: 上の覆いの外観（襟が前へ 7 mm 伸びる。フードの上に薄い殻が乗る）。
- **Design（次）**: 動く覆い（頭側の可動フラップ + ばね）の概念、首側の詰め物（上の輪）を殻でなく実形にした場合の量、ストッパーの荷重の形。

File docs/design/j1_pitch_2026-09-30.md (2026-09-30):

# J1 ピッチ — 暫定範囲 −5°〜+10° でのすき間（2026-09-30）

> **【2026-09-30 夜 訂正】この文書の姿勢ラベル（p7 = −5°、p8 = +10° など）は CAD の符号で、+ が頭を下げる。「負 = 頭を下げる」は誤り。Engineering の符号（+ = 頭を上げる）への読み替えと、範囲の端の数（−5° = 401、+10° = 1562 mm³）は `j1_sign_correction_2026-09-30.md`。本文は消していない。**

> **【常に先頭に置く注意】現行の CAD（KNUCKLE DRUM のみ）では、まっすぐ（124 mm³）に比べ、曲げた姿勢で 2250〜2939 mm³ のすき間の体積が残る（約 20 倍、18〜24 倍）。** 背板の層（約 1020 mm³/姿勢）は、この文書の案 (a)(b) をまだ採っていないので**現行 CAD では未解決のまま**。J1 ピッチは範囲の確認待ち。数値は CAD_CONCEPT / KINEMATIC_SIM（外形 STL のみ、内部部品・公差・たわみなし）。**安全・合格の語は使わない。** 5.7 N・0.25 N·m は暫定（SAFETY_UNVERIFIED）。

Engineering の暫定範囲（ENTRY-E-0006）: **−5°〜+10°**（Design の CAD の符号: **負 = 頭を下げる**）。取り込み機構は作業中 **0° 付近**（上げ角 +0.8〜+1.3° 以内）。

## 1. 頭の後ろの穴のすき間（埋め物あり、KNUCKLE DRUM は関係なし。0.5 mm）

| J1 ピッチ | 危険体積 mm³ | r の範囲 mm（5〜95%） | 軸まわりの角 | 幅 mm |
|---|---|---|---|---|
| -45° | 856 | 5.5〜44.5（6.7〜32.6） | -75°〜45° | 5.0〜9.0 |
| -22° | 1228 | 10.4〜43.7（14.3〜18.7） | -52°〜22° | 5.2〜7.8 |
| -10° | 1562 | 23.9〜43.8（24.4〜34.1） | -44°〜79° | 5.0〜10.0 |
| -5° | 601 | 25.4〜43.8（25.9〜34.2） | -40°〜84° | 5.0〜7.0 |
| -3° | 44 | 33.8〜43.7（33.8〜34.7） | -35°〜86° | 5.0〜5.7 |
| -2° | 10 | 34.1〜44.0（34.1〜43.7） | -33°〜87° | 5.2〜6.1 |
| -1° | 10 | 34.1〜43.9（34.1〜43.7） | -33°〜88° | 5.0〜6.4 |
| +0° | 2 | — | — | — |
| +1° | 3 | — | — | — |
| +2° | 40 | 43.4〜50.5（43.4〜50.5） | 16°〜92° | 5.0〜7.5 |
| +3° | 105 | 43.4〜50.6（45.9〜50.6） | 16°〜93° | 5.0〜8.5 |
| +5° | 401 | 42.9〜51.1（46.0〜50.9） | 16°〜95° | 5.0〜8.5 |
| +7.5° | 1350 | 43.1〜51.7（45.9〜51.1） | 15°〜97° | 5.0〜9.2 |
| +10° | 2062 | 43.2〜51.9（45.5〜51.3） | 15°〜99° | 5.0〜11.3 |
| +22° | 4307 | 45.0〜52.0（45.6〜51.7） | 15°〜37° | 5.0〜9.5 |

- **±小さい角度でも 0 でない**。**−2° 〜 +1° は 10 mm³ 以下**（ノイズの範囲）。−3° で 44、+2° で 40、+3° で 105、**+5° で 401、+7.5° で 1350**、範囲の端 **−5° で 601、+10° で 2062**。
- **下げる側（−）** は r = 25〜44 mm（首の下の後ろのくさび、x −162〜−153、z 12〜19）。**上げる側（+）** は r = 43〜52 mm（VISOR のフード R 46〜48 と襟の輪、x −141〜−133、z 45〜52、|y| ≤ 26）。
- **範囲（−5〜+10°）の端で 601 / 2062 mm³ が残る。範囲の中は、−2〜+1° を除いて 0 でない。**

## 2. 提案

| 項目 | 内容 | 状態 |
|---|---|---|
| **作業窓** | **−2°〜+1°**（すき間 ≤ 10 mm³）。取り込み機構の要求（+0.8〜+1.3° 以内）と重なる | Engineering の確認待ち |
| **機械ストッパー** | 範囲の端（−5° / +10°）で止める。首の芯（VISOR の舌）の扇の切り欠きの端面を当て面にする（ヨーク側で荷重を受け、頭巾では受けない、ENTRY-D-0001 (3) と同じ）。**扇の幅 = 15°（−5〜+10）+ 頭の塊の角度幅 + 余裕**。ストッパーの実体の角度・強度は未設計 | 概念のみ |
| **箱形カバー（案 1 つ）** | 首の襟の前縁を、フードの上へ**同心の殻（R 49.5〜51.1、厚さ 1.6）として +10° 分（r 50 で約 9 mm）前へ延ばす**（上げる側の r 43〜52 の輪）、下の後ろは、頭の塊の後ろの下に**首につく薄い受け板**を足して、下げる側のくさびの口を覆う。全体が「頭の後ろの穴を覆う箱」 | **未検査**（形も STL も作っていない。前回のあごのフラップが幅不足で効かなかった経験から、幅は穴の全幅 ±30 が要る） |

## 3. 取り込み機構との関係（頭の口の高さ）

J1 軸（−181.8, z 32.4）から口の下の前縁（x −236、床）まで **63.1 mm**（水平 54.2、垂直 32.4）。頭を **+θ° 上げると、口の前縁が床から持ち上がる**（`32.4(1 − cosθ) + 54.2 sinθ`）:

| θ | 口の前縁の持ち上がり mm |
|---|---|
| −5° | −4.6（床にめり込む = 胴が持ち上がる） |
| −2° | −1.9 |
| 0° | 0 |
| +1° | 0.95 |
| +1.3° | 1.24 |
| +2° | 1.9 |
| +5° | 4.9 |
| +10° | 9.9 |

Engineering の t・c（段差 0〜1.0、すき間 0〜1.0 mm）と比べると、**持ち上がりが 1 mm を超える +1.1° 以上は、口の下に隙間ができる**。作業窓 −2〜+1° は、すき間の面でも取り込みの面でも整合する。

## 4. 限界

- 外形 STL のみ。**範囲の端の 601 / 2062 mm³ は、カバー・ストッパーが無い現行 CAD の数**。箱形カバーは未検査。安全・合格の語は使わない。

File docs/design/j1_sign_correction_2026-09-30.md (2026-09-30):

# J1 ピッチの符号の訂正 — すき間の表（p* ラベル）は「+ が頭を下げる」— 2026-09-30

> **【先頭の注意】KNUCKLE DRUM 後も、まっすぐ比で約 20 倍（18〜24 倍）のすき間が残る。背板は現行 CAD では未解決のまま。5.7 N・0.25 N·m は暫定（SAFETY_UNVERIFIED）。安全・合格の語は使わない。**
> 数値は CAD_CONCEPT / KINEMATIC_SIM。**Design の見積もり（Engineering 未検証）**。過去の文書は消していない。この文書が優先する。

## 何が違ったか

- `j1_pitch_2026-09-30.md`、`gap_pitch.py` の姿勢ラベル（p7 = −5°、p8 = +10° など）は、**姿勢の変換（`transforms.json`）の符号**。頭の前面の点（x −236、z 40）に各姿勢の変換を掛けると:

| ラベル（CAD の符号） | 前面の点の z（mm、もとは 40） | 実際の向き |
|---|---|---|
| p4 −45° | 76.1 | **頭が上がる**（鼻上げ） |
| p6 −10° | 49.3 | 上がる |
| p7 −5° | 44.7 | 上がる |
| p0 0° | 40.0 | — |
| p14 +2° | 38.1 | 下がる |
| p8 +10° | 30.5 | **頭が下がる**（鼻下げ） |
| p9 +22° | 19.1 | 下がる |

- **CAD の符号は「+ が頭を下げる」**（CAD.md にも「J1 の符号は未確定」とある）。`j1_pitch` の「Design の CAD の符号: 負 = 頭を下げる」は**誤り**。
- **Engineering の符号は「+ が頭を上げる」**（口の前縁が +0.95 mm/° 上がる）。**口の高さの表（j1_pitch §3、mouth_front_layout §4 (3)）は Engineering の符号で正しい**が、**すき間の表（同 §1）は CAD の符号のまま**だった → 2 つの表の符号が逆だった。

## 読み替え（Engineering の符号 θ_E = −θ_CAD）

| Engineering の θ_E（+ = 頭を上げる） | CAD のラベル | 危険体積 mm³ | すき間の場所 |
|---|---|---|---|
| **−5°（頭を下げる。範囲の端）** | +5° | **401** | 上げ側の輪（r 43〜52、フードと襟） |
| **−2°** | +2° | 40 | 同上 |
| −1° | +1° | 3 | — |
| 0° | 0° | 2 | — |
| +1° | −1° | 10 | 下の後ろのくさび |
| +2° | −2° | 10 | 同上 |
| +3° | −3° | 44 | 同上 |
| +5° | −5° | 601 | 同上（r 25〜44） |
| **+10°（頭を上げる。範囲の端）** | −10° | **1562** | 同上 |

- **範囲の端は 401（下げ 5°）と 1562（上げ 10°）**。前に書いた 601 / 2062 は入れ替わっていた。
- **作業窓「Engineering の −2〜+1°」は最大 40 mm³**（−2° = 40）。前に書いた「≤ 10 mm³」は CAD の符号の窓（−2〜+1°）の数。**取り込みの窓（θ_E −0.1〜+0.9°）は ≤ 10 mm³**（変わらない）。
- 上げ側（頭を上げる）のすき間は「下の後ろのくさび」（首の下の斜面と頭の後ろ下の先端）、下げ側は「上の輪」（フードの後ろ端が襟から離れる）。

## 影響のある過去の記述

- `j1_pitch_2026-09-30.md` §1 の表の符号列（上を読み替え）、§2「機械ストッパー」の向き、「下げる側 / 上げる側」の説明が逆。
- ENTRY-D-0006 / D-0007 / D-0008 の J1 の数（601、2062、−2〜+1° で ≤ 10 mm³）。ENTRY-D-0010 で訂正を出す。
- 口の高さ・スキッドの説明（θ_E で書いたもの）は正しい。
- **確認のお願い（Engineering）**: J1 の実機の符号（+ = 頭を上げる）を、CAD と一致させる（Design の CAD の姿勢変換は「+ = 下げ」）。

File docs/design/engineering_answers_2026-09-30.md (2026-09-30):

# ENTRY-D-0006 の確認事項 4 点への回答（c の基準・J1・ToF・照明の合成視覚）— 2026-09-30

> **【2026-09-30 夜 追記・位置づけの訂正】この文書の J1 の受動的な柔らかさ、ToF の役割、LED 移設の効果の結論は、すべて「Design の見積もり（Engineering 未検証）」である。** Engineering の答えではなく、Design が Engineering の HG-H1・HG-H2 の prior・シミュを**読み出しのみ**で走らせた結果。本文中の「確定」「再発しない」「使えない」「最良」「推奨」は、**Design の読み・提案**と読み替える。確認は下の §6 で Engineering に依頼として残す。本文は消していない（履歴として残し、この追記と §6 だけを足した）。

> **【常に先頭に置く注意】現行の CAD（KNUCKLE DRUM のみ）では、まっすぐ（124 mm³）に比べ、曲げた姿勢で 2250〜2939 mm³ のすき間の体積が残る（約 20 倍、18〜24 倍）。** 背板の層（約 1020 mm³/姿勢）は現行 CAD では未解決のまま。J1 ピッチは範囲の確認待ち。数値は CAD_CONCEPT / KINEMATIC_SIM / ACTUATOR_MODEL_SIM / SYNTHETIC_VISION_SIM / 一次資料（データシート）。**結果が悪くても後付けの調整はしていない。5.7 N・0.25 N·m は暫定（SAFETY_UNVERIFIED）で、安全の確定としては扱わない。**

出所: Engineering の `simulation/hardware_gaps/HG-H1_actuator`・`HG-H2_sensor_head`・`simulation/h2_vision.py`・`h2_pose_from_line.py`（`agent/engineering-vision-sim` のスナップショットを**読み出しのみ**で作業領域へ展開。Engineering のファイルは変更していない。Design の実行スクリプトは `tools/h2_layout_compare.py`、`tools/j1_resolution_check.py`）。

## 1. c の基準 — 床から測る（Design の読み: 一致した。Engineering の確認待ち）

- User の指示（clearance_mm と同じ、板があっても基準は床）は、Design が `common.py`・`passive.py` から読んだ定義と**一致**。壁の下端 z = c（床から）、板は下面 c・上面 c + t、物が見る段差 = c + t。**Design の見積もりとして**、Design は `mouth_front_layout_2026-09-30.md` §4 (1) と B2 の訂正（`test_piece_b/B2/CORRECTION_2026-09-30.md`）をそのまま採る。
- 補足（確定に影響しない）: シミュの板は下面が床から c 浮いた板（実物は下面が床に付く板で、厚さ c + t にして同じ段差を作る）。

## 2. J1 の分解能と柔らかい追従（HG-H1 の prior で見積もり = Design の見積もり（Engineering 未検証））

**前提の限界**: HG-H1 は**トルク上限・ストール・熱・バックドライブ・反射慣性**の prior を持つが、**位置制御の kp・不感帯・バックラッシは持たない（UNKNOWN）**。ここでも仮定しない。kp で許容できる範囲は「必要な剛性の要件」までしか出せない。

| 量 | 値 | 由来 |
|---|---|---|
| 分解能 | 4096 / 回転 = **0.0879° / ステップ** | `docs/sts3215_registers.md` |
| 1 ステップの高さ | 口の前縁 **0.083 mm**、カメラ 0.077、横スキッドの前端 0.068、後ろのスキッド 0.027 | 軸から前縁 54.2 mm 等 [C] |
| 窓のステップ数 | すき間の面 −2〜+1° = **34 ステップ**。**取り込みの面（c ≤ 1.0、前縁が床に触れない）は 12 ステップ**（c₀ によらず。0.95 + 0.106° = 1.06°） | [C] |
| 量子化の誤差 | ±0.5 ステップ = 口の前縁で **±0.042 mm**、前後（60 mm）の高さの差 **0.046 mm** | c₀ = 0.1 の半分以下 → **分解能だけなら口の下端の前後の平行（ピッチ）は c₀ の範囲で保てる** |
| トルク上限（既定の比 0.167） | 公称 0.449 N·m、prior の幅 **0.14〜0.70 N·m**（ストール 1.4〜3.0、e ±40 %） | HG-H1 `assumptions.yaml` |
| 上限が押す力（横スキッドの前端、腕 44.2 mm） | 公称 **10.2 N**（3.2〜15.9 N） | 上限 ÷ 腕 [C] |
| バックドライブ | prior 0.05〜0.50 N·m。**頭の重力モーメント 0.024〜0.035 N·m（E-0006）より大きい** | HG-H1 prior（UNKNOWN） |

**読み**:

1. **口の下端が床と平行（ピッチ）を保つ**: 分解能では足りる（±0.04 mm）。**実際の精度は不感帯・バックラッシ（未測定）が決める**。ロール（左右）は J1 にない → 左右の横スキッドの底の高さ（やすり掛けで ±0.05）と床で決まる。
2. **「柔らかい追従」は、受動には成り立たない**: prior のバックドライブ（≥ 0.05 N·m）が頭の重力モーメントより大きいので、**頭は自重ではスキッドに降りない**（サーボが位置を保つ）。→ **能動の追従**が要る: (a) 床に触れるまで J1 をゆっくり下げ、上限に達した（電流・位置の遅れ）角度を「床の接触角」として記録する（**床接触の較正**）、(b) そこから c に相当するステップだけ上げる（c₀ = 0.1 → 1 ステップ、0.3 → 4、1.0 → 12）、(c) 作業中の上限は小さく。
3. **作業中のトルク上限**: 横スキッドを床へ押す力を頭の重さ（約 1 N）以下に抑えるなら、**上限 ≲ 0.022 N·m**（ストールの 0.82 %、レジスタ比で約 8.2 ‰ の公称）。prior の誤差（ストール ×e）で実効 **0.007〜0.034 N·m、押す力 0.16〜0.78 N**。**この上限は、バックドライブの最小 0.05 N·m ÷ 0.0442 m = 1.13 N より小さい**（余裕 1.4 倍）→ 上限を超える押し込みでは頭が動かず、**口の前縁は床に届かない**。
4. **マイナス側で段差が再発するか**: 既定の上限（0.449 N·m、押す力 10 N）で −θ を指令し続けると、バックドライブ（0.05〜0.5）を超えて頭が回り、**前縁が横スキッドの前端より 10 mm 前（腕 54.2 対 44.2）にあるため、θ が 0.57° 進むと前縁が床に触れる**（c₀ = 0.1）→ **段差（引っ掛かる縁）が再発する**。**作業中の上限を ≲ 0.022 N·m に落とせば再発しない、という見込み（Design の見積もり。バックドライブ・不感帯が UNKNOWN のため未検証）**。ただし実効上限の不確かさ（e ±40 %）とバックドライブ（UNKNOWN）は**実測が要る**。
5. 未確認（HG-H1 の `hardware_test_plan.md` に無い）→ **追加の測定を提案**: (i) J1 のバックラッシと不感帯（±1° 往復、上限 0.02 N·m）、(ii) 上限 0.02 N·m での実際の押す力（ばね秤、腕 44 mm）、(iii) 床接触の較正の繰り返し精度。

## 3. ToF（下向き）— VL53L1X のデータシート（一次資料の値）と、その読み（Design の見積もり（Engineering 未検証））

出所: ST `VL53L1X` データシート（DS12385）<https://www.st.com/resource/en/datasheet/vl53l1x.pdf>（本文を取得して確認。**§7.3、Table 17〜20**）。

| 項目 | データシートの値 |
|---|---|
| 最短の測定距離 | **「保証する最短距離は 4 cm。これより近いと、センサーは物を検出するが測定は正確でない」**（§7.3） |
| 測定誤差 | **±20 mm**（暗い環境、Table 17・19）、**±25 mm**（環境光 200 kcps/SPAD、Table 18・19）（誤差 = 精度 + 繰り返し。距離ごとの表は無い） |
| 繰り返し性 | ±1 % 〜 ±0.15 %（タイミング予算と環境光による、§7.2） |
| 視野 | 標準 27°（ROI 4×4〜16×16 で 15〜27°、Table 20） |
| 最短のタイミング予算 | 20 ms（短距離モードのみ）、33 ms（全モード） |

**評価**:

- **数 mm の高さは測れない**。取付け高さ 6〜9 mm は最短距離 40 mm の 1/5 で、**データシートは精度を保証しない**。**40 mm より遠くても誤差 ±20〜25 mm** → **c・t（0.1〜1.0 mm）の確認に ToF は使えない**（どこに置いても。頭の全高が 80 mm 以下で、床に向いた ToF は 40 mm より近いか、遠くても ±20 mm）。
- **代替: `pose_from_line`**（EXP-ENG-VIS-0003、SYNTHETIC）: 床の線から**カメラ高さ ±0.6 mm（最大 1.0）、pitch ±0.4°（速度改善後 最大 0.75 mm / 0.23°）**。口の前縁の高さへの換算: 高さ 0.6 と pitch 0.23〜0.4° × 腕 50〜54 mm（0.2〜0.38 mm）の二乗和 = **0.64〜0.71 mm**。**c = 0.1〜1.0 mm・窓の端（+0.95 mm）を判定するには足りない**（分解能が窓の幅と同程度）。使える範囲: **頭が 1.5〜2 mm 以上沈む・浮く**（毛足・絨毯・持ち上げ）の検出と、J1 の角度の読み値の**事前分布との突き合わせ**（Engineering の記述どおり）。
- **c・t の担保は、J1 の角度（0.083 mm/ステップ）＋ 床接触の較正 ＋ スキッドの底**（§2）。ToF・線光は**粗い検証**。
- **ToF を空洞の外へ移す案（口の左右の外側／後ろ）の測定範囲への影響**: (a) 測定の質は**変わらない**（どこでも最短距離未満）。(b) **使い道は「床が遠ざかった（崖・段差）」の 2 値**（床が 4 cm 未満 = 無効・近い、崖で 4 cm 以上の有効値に変わる、という**状態変化**。データシートに保証は無い = 推測 [C]）。(c) その用途は**口に近いほどよい**: 奥の壁の後ろ（口から 64 mm）だと、口が崖を越えてから検出する。**口の前の外側の角（x −236、|y| 36）か、横スキッドの前端（x −226、|y| 40）**に置くと 0〜10 mm 遅れで済む（LED と同じ角に同居させる）。視野 27°・高さ 6〜8 mm の床の径は 約 3〜4 mm。

## 4. 斜め LED の移設と合成視覚（HG-H2、SYNTHETIC_VISION_SIM）— Design の見積もり（Engineering 未検証）

条件: Engineering の `h2_vision.run_trial`（`physical_falloff=1`・`flat_field=1`・`auto_exposure=1`、UXGA×0.5、**1 条件 = 対象 11 種 × 8 回（88）+ 陰性 3 種 × 8 回（24）**、乱数の種は全条件で同じ）。LED は世界座標で置き換え（`LED_LAYOUTS` に足す。Engineering のファイルは変えない）。**hood の壁の遮りは HG-H2 のモデルに無い**ため、「現行位置 + フード」は斜めの明るさを 12 %（遮られない光線の割合）にした**近似**。

| 条件（斜め LED の位置） | 照度比（点光源、フードの遮り込み） | 巡回（patrol）検出 | 停止（inspect）検出 | **危険物（critical）inspect** | 鏡面の危険物を「危険」と判定 | 誤報（巡回 / 停止） | 大きさ誤差（中央） | 位置誤差（中央 mm） |
|---|---|---|---|---|---|---|---|---|
| **移設前**（頬の下 X−212、\|y\| 40、Z7）= Engineering の `design_2x2` | 14.7 倍（フードなし） | **0.82** | 1.00 | **1.00** | 0.91 | 0 / 0 | 0.10 | 6.1 |
| 現行位置 + フード（**近似**: 明るさ 12 %） | 60/330 点が真っ暗、19.9 倍 | **0.00** | 1.00 | 1.00 | 0.91 | 0 / 0 | 0.43 | 5.1 |
| **移設後 ①** 口の前の外側の角（X−236.5、\|y\| 36、Z6） | 35.4 倍 | **0.89** | 1.00 | **1.00** | 0.84 | 0 / 0 | 0.23 | 5.6 |
| 移設後 ① の Z4（低め） | 36.0 倍 | 0.93 | 1.00 | 1.00 | 0.84 | 0 / 0 | 0.16 | 5.8 |
| 移設後 ① の Z9（高め） | 34.1 倍 | **0.45** | 1.00 | 1.00 | 0.84 | 0 / 0 | 0.23 | 5.8 |
| **移設後 ②** 横スキッドの前端（X−226、\|y\| 40、Z6） | **17.4 倍**（1/330 点のみ暗い） | **0.94** | 1.00 | **1.00** | 0.84 | 0 / 0 | 0.16 | 5.6 |

**読み**:

- **危険物（critical）・停止・誤報は、移設前後で同じ**（1.00・1.00・0/0）。**巡回は移設前 0.82 → 移設後 0.89〜0.94 で保たれる**（近似のフード遮りありの現行位置は 0.00 = **現行位置のままフードを付けると巡回が消える**）。
- **悪化する指標**: 鏡面の危険物を危険と判定する割合 **0.91 → 0.84**（鏡面の危険物 4 種 × 8 回 = 32 回のうち 29 → 27 回、差は 2 回。**N が小さく、差は有意とは言えない**）、大きさ誤差（中央）0.10 → 0.23（高さ Z6）/ 0.16（Z4、横スキッド前端）。
- **LED の高さは 6 mm 以下が要る**: Z9 で巡回 0.45（Engineering の以前の所見: 影は LED の高さに依存）。
- **移設後 ② の横スキッドの前端**が、照度比（17.4 倍 ≈ 前の 15 倍）・巡回（0.94）とも最良。**Design の案を ① → ② に変える（Engineering 未検証。決めるのは Engineering の HG-H2 の再走査と User）**（フードの前の角ではなく、横のスキッドの前端に LED を入れる。スキッドは口の外側 |y| 36〜44 の案と同居）。
- **悪化への対策案（1〜2 個。後付けの調整ではなく、位置の選択として）**: (i) **LED を横スキッドの前端（②）へ**（上のとおり。追加の部品なし）、(ii) 鏡面の危険物の判定が落ちるなら、**通常照明の 2 灯目（口の線の前端 X−232、\|y\| 41、Z21、照度比 20.9 倍）**を検討（未検証。HG-H2 で `normal` の位置を変えて確認）。
- **限界**: 合成画像（実写ではない）、フードの遮りは近似、LED の配光・スキッドの影・実物の反射は入っていない。**実写の確認が要る**。

## 5. 次にやること

1. Engineering: J1 の不感帯・バックラッシ・上限 0.02 N·m の実測（H1 の試験計画に追加）、床接触の較正の手順、ToF の用途（崖の 2 値）と置き場所（横スキッドの前端）。
2. Design: 斜め LED を横スキッドの前端へ変更する案を `mouth_front_layout` に反映（Fusion がつながったら CAD）。
3. User: 変更なし（顎板・スキッドの外観の確認は前回から継続）。

## 6. Engineering への確認依頼（Design は答えを決めない）

Design の見積もり（上）を、Engineering の側で確認・訂正してほしい項目。**確認されるまで、本文の結論は未検証のまま。**

1. **c の基準（床から）と、板の位置（空間のみ、下面 c）**: Design の読みは `common.py`・`passive.py` と一致。Engineering の定義として間違いがないか。
2. **J1**: (a) HG-H1 に kp・不感帯・バックラッシの prior を足すか（今は UNKNOWN）、(b) バックドライブが頭の重力モーメントより大きい（prior）ため受動の追従は成り立たない、という読みの確認、(c) 作業中の上限 ≲ 0.022 N·m で負側の段差が再発しない、という見込みの確認、(d) 床接触の較正の手順。
3. **ToF**: 「c・t の担保に使えない」「用途は崖の 2 値」という読みの確認、置き場所（横スキッドの前端）の可否。
4. **LED 移設**: 「巡回 0.82 → 0.89〜0.94、鏡面の危険物の判定 0.91 → 0.84」は Design が Engineering の `run_trial` を**未変更のまま**走らせた値（N が小さい、フードの遮りは近似）。Engineering の HG-H2 で、フードの遮りを入れた再走査と、位置（①/②）の比較。
5. **いずれも 5.7 N・0.25 N·m は暫定（SAFETY_UNVERIFIED）のまま**。

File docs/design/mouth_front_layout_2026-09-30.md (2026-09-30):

# 口の前に床に触れる部品を置かない配置 ＋ ENTRY-D-0006 の確認事項への回答（2026-09-30）

> **【常に先頭に置く注意】現行の CAD（KNUCKLE DRUM のみ）では、まっすぐ（124 mm³）に比べ、曲げた姿勢で 2250〜2939 mm³ のすき間の体積が残る（約 20 倍、18〜24 倍）。** 背板の層（約 1020 mm³/姿勢）は現行 CAD では未解決のまま（案 (a)(b) は `plate_layer_2026-09-30.md`、まだ採っていない）。J1 ピッチは範囲の確認待ち。数値は CAD_CONCEPT / KINEMATIC_SIM / GEOMETRY_SIM（外形・箱・点光源のみ）。**安全・合格の語は使わない。** 5.7 N・0.25 N·m は暫定（SAFETY_UNVERIFIED）。

> **Fusion は今回の作業中に切断され、CAD は変更していない**（この文書の配置は Python の箱の検査。次に Fusion がつながったら §6 の手順で CAD に入れる）。既存ファイルは上書きしていない（B2 の訂正は別ファイル `test_piece_b/B2/CORRECTION_2026-09-30.md`）。

## 0. 結論（先に）

1. **口の前（口の幅 60 + 足の帯 = 掃引幅 |y| ≤ 34、口の面〜奥の壁の外、屋根の高さ 16.6 mm 以下）に入る部品は、現行で 5 つ・合計 15,290 mm³**（REF の頭のスキッド 5,400、双子スキッド 5,530、顎板 3,432、ToF 下向き 648、REF の斜めの LED 280）。**案では 0 mm³**（横のスキッド |y| 36〜44、後ろのスキッド 2 つ、ToF・LED を口の外へ）。
2. **c は床から測る**（Engineering のシミュのコードで確認）。**段差の板は「空間の中だけ」に、下面が床から c、上面が c + t。物が見る段差は c + t。** 私の試験片 B2 の「板の前縁を口の面に置く・板の上面から c」は**誤り**。訂正版（`test_piece_b/B2/CORRECTION_2026-09-30.md`、`B2/print_corrected/`）を作った。
3. **J1 の作業窓 −2〜+1° は、すき間（≤ 10 mm³）の面だけの数字。取り込みの面では −0.1〜+0.9° まで狭い**。マイナス側は口の前縁が床に**めり込む**（c = 0.1 で −0.106°）。**スキッドで頭を支えて、J1 は柔らかく追従させる**形にする。
4. **頬の下の LED を口の前の外側の角へ移すと、遮りは 0 になるが、照度比は 15 → 35 倍に悪化**（現行位置のままフードを付けると 60/330 点が真っ暗）。

## 1. 規則と禁止域

- **禁止域 F**: x = −240（口の面 −236 の前 4 mm）〜 −174.4（奥の壁の外）、|y| ≤ 34、z ≤ 16.6。**F に入る部品は、口へ入る物（高さ 15 以下）に当たる = 段差になりうる**。
- **許容**: (i) |y| ≥ 36 の外側、(ii) 奥の壁より後ろ（x ≥ −172）、(iii) 屋根より上（z ≥ 16.6）。
- **床に触れる部品は、F の外**（横のスキッド・後ろのスキッド）。**口の下端（足の帯の底）は、J1 = 0° で床と平行**（スキッドの底面と同一平面から c だけ上、下の §3）。

## 2. 現行と案（箱の重なり [C]。`tools/mouth_layout_check.py`、図 `assets/mouth_layout_2026-09-30.png`）

| 部品（由来） | 現行の位置（x、\|y\|、z mm） | F との重なり mm³ | 案 |
|---|---|---|---|
| REF 頭のスキッド（Engineering PROVISIONAL） | −230〜−200、≤ 18、0〜5 | **5,400** | **廃止**（口の下は空洞 = 床が床） |
| 双子スキッド（Design LIGHT+SKID） | −232〜−172、30〜40、0〜12 | **5,530**（足の帯 \|y\| 34 まで） | **横のスキッドへ**（下） |
| 顎板 2 枚（Design CHIN SHIELD） | −232〜−180、20〜31、1〜4 | **3,432** | **廃止**（足の帯 3.6×4 が顎板の役） |
| REF ToF 下向き | −200〜−182、≤ 9、5〜7 | **648** | **奥の壁の後ろ**（−172〜−165、≤ 7、7〜9） |
| REF 斜めの LED（FW03 位置） | −232〜−227、15〜22、5〜9 | **280** | Design E3 では頬の下へ移し済み → **口の前の外側の角**（下） |
| 頬の下の LED（Design E3） | −215〜−210、38〜42、5〜10 | 0 | **漏斗の壁に隠れる**ので移す（§4 (5)） |
| 鼻のカメラ窓の枠（D14） | −237〜−235、≤ 7、23〜37 | 0（z 23 > 16.6） | 変更なし（**床から 23 mm**、段差にならない） |
| 口の線（Design E3） | −236〜−207、27〜47、20〜23 | 0 | 変更なし（屋根の上 3.4 mm） |
| REF IR LED | −232〜−228、11〜17、25〜31 | 0 | 変更なし |
| **案: 横のスキッド（口の左右の外側）** | **−226〜−178、36〜44、0〜10** | 0 | 口の面から 10 mm 後ろから始め、**前端は R6 で反らす**。足の帯（\|y\| 34）との間 2 mm。あごの底面（\|y\| 36〜44 で z 10〜19）に接合 |
| **案: 後ろのスキッド 2 つ（奥の壁の後ろ）** | **−172〜−164、14〜22、0〜7** | 0 | あごの底面（z 6〜9）に接合 |
| **案: ToF 下向き** | **−172〜−165、≤ 7、7〜9** | 0 | 後ろのスキッド 2 つの間。**窓は床から 7〜9 mm**（§4 (2)） |
| **案: 斜めの LED** | **−237〜−233、36〜38、4〜8** | 0 | 口の前の外側の角。足の帯（\|y\| 34）の外 |
| **合計** | 現行 **15,290** | | 案 **0** |

支持: **横のスキッド 2 本 + 後ろのスキッド 2 つの 4 点**（x −226〜−164、\|y\| ≤ 44 の四角）。頭の質量 約 90 g（`config/robot.yaml`）の重心は、この四角の中に入る見込み（重心位置は未確認）。

## 3. 「J1 = 0° で口の下端が床と平行」の作り方

- **足の帯の底と、スキッドの底を、頭の座標で同一の水平面の上に置く**: スキッドの底 = 床（z 0）、足の帯の底 = z c₀（シミュの既定 0.1 mm）。**スキッドが c₀ だけ下へ出る**ので、頭はスキッドで床に乗り、フードは床から c₀ 浮く。
- J1 = 0° は、首の芯が胴と平行な姿勢（CAD の中立）。頭の座標がこの姿勢の水平に対して作ってあれば、足の帯の底は自動で床と平行。**公差**: 4 つのスキッドの底の高さの差 0.05 mm は、支持の間隔 62 mm で傾き 0.05° = 口の前縁で 0.05 mm（c₀ の半分）→ **スキッドの底をやすり掛けで同一面に**（B2 の README と同じ手順）。
- **頭は J1 で床に押し付けない**: 頭の高さはスキッドが決める。J1 は 0° を指令し、**トルクを小さく（柔らかく）**して、床の凸凹・胴の傾きに頭がスキッドで追従する（Engineering の確認）。

## 4. ENTRY-D-0006 の確認事項への回答

### (1) c の基準面（Engineering のシミュの定義と揃える）

**シミュのコード**（`simulation/scoop/forms/common.py` の `hood()`、`passive.py`、`config/scoop.yaml`。`agent/engineering-scoop`、読み出しのみ）:

- 壁の下端 z = **c（床から）**。板が無いとき、空間の床 = 床（z 0）。
- 板があるとき（`plate` = t）: **板の geom は z = c 〜 c + t**（下面が床から c、上面が c + t）、**壁の下端は c のまま（床から）**。空間の床の高さ zb = c + t。板は**空間（x 0〜30、\|y\| ≤ 15）の中だけ**で、**漏斗（口の前 30 mm）には板が無い**（漏斗の床は床のまま）。
- **したがって: c は床から測る。板の上面からではない。物が見る段差 = 床から板の上面まで = c + t。**（既定 c = 0.1 のとき、t = 0.1 の段差は 0.2 mm。Engineering の「t = 0.1 で 0 %」は、実質 c + t = 0.2 mm の段差。）

**B2 への影響（Design の誤り）**: B2 は (i) 板を**足の帯の下・口の面から敷く**、(ii) c を**板の上面から**とした。シミュは (i) 板は**空間の中だけ、前面は空間の入口（口の面から 30 mm 奥）**、(ii) c は**床から**。→ **訂正版**（`CORRECTION_2026-09-30.md`）: **空間の床の板（29.6×29.6、厚さ T = c + t）を、フードの壁の間の床に置く**（物が見る段差は同じ）。パッド（c）は今のまま。**B2 のフード本体・パッドは変更なし**（板だけが訂正）。

### (2) ToF（下向き）を空洞の外へ移す案

- **可**。空洞の外（奥の壁の後ろ）の **x −172〜−165、\|y\| ≤ 7、z 7〜9** は、空洞・掃引幅・下の後ろの埋め物（x ≥ −162、z ≥ 9.6）のいずれとも重ならない（重なり 0 mm³）。後ろのスキッド 2 つの間に置ける。
- **高さ測定の要件（Design から Engineering へ）**: (a) **この位置の ToF は床から 7〜9 mm**。一般的な単点 ToF の最短測定距離は数 cm のことが多く、**この高さでは床が測れない可能性**がある → **部品の最短測定距離を確認**（Design は型番を知らない）。(b) **c・t（0.1 mm 単位）の確認には ToF は使えない**（分解能が 1 mm 級）。**口の高さは J1 の角度と、スキッドの底の高さで決まる**（口の前縁は J1 1° で 0.95 mm）。(c) この位置の ToF は**口から 64 mm 後ろの床**を見る。**前方の段差・崖の検出には使えない**（前方は別のセンサー）。(d) 空間の中の物の有無は、屋根の下面からの下向き（屋根から床 15 mm）も候補だが、(a) と同じ最短距離の問題がある。

### (3) J1 の作業窓と機械ストッパー角

**口の下端の高さ**（J1 軸 (−181.8, z 32.4) まわりの回転、床から 0.1 mm 浮いた足の帯が J1 = 0° で水平、+ = 頭を上げる）。単位 mm、床からの高さ:

| J1 | 口の前縁 x −236 | 空間の入口 x −206 | 奥の壁 x −176 |
|---|---|---|---|
| −2° | **−1.77（床の下）** | **−0.72（床の下）** | 0.32 |
| −1° | **−0.84（床の下）** | −0.32（床の下） | 0.21 |
| −0.5° | −0.37（床の下） | −0.11（床の下） | 0.15 |
| −0.1° | 0.0（接触） | 0.06 | 0.11 |
| 0° | 0.10 | 0.10 | 0.10 |
| +0.5° | 0.57 | 0.31 | 0.05 |
| **+0.95°** | **1.00** | 0.51 | 0.01 |
| +2° | 2.01 | 0.96 | −0.08 |

- **マイナス側**: 口の前縁は**床にめり込む**（c₀ = 0.1 で **−0.106°**、c₀ = 0.3 で −0.32°、c₀ = 1.0 で −1.06°）。**頭を床に押し付ける**ことになり、前縁の底（面取り 0.3）が床に食い込む。**床は動かないので、頭が前縁を軸に回り、奥が浮く**（−1° で奥の壁の下 1.15 mm、−2° で 2.2 mm: 1 円玉（厚み 1.5）が奥の下をくぐりうる）。**「壁の下端が床に触れて段差になる」恐れは、ある**（前縁の接触は、床の凹凸で引っ掛かる縁になる。絨毯は未対応）。
- **プラス側**: c の実効 = c₀ + 0.95 mm/° × θ。**c ≤ 1.0 を守るのは +0.95°（c₀ = 0.1）、+0.74°（c₀ = 0.3）まで**。
- **作業窓**: すき間の面（≤ 10 mm³）は **−2〜+1°**、取り込みの面（c ≤ 1.0、前縁が床に触れない）は **−0.1〜+0.9°**（c₀ = 0.1）。**両方を満たす窓 = −0.1〜+0.9°**（**J1 の角度の分解能 0.088°（12 ビット 4096/回転の場合。Engineering の確認）の約 1 ステップの余裕しかない**）。→ **窓を J1 の角度で守るのは難しい。スキッドで頭の高さを決め、J1 は 0° 指令で柔らかく** が現実的（§3）。
- **機械ストッパー角**: 取り込み中の窓は J1 で**守れない**ので、ストッパーは窓のためでなく**範囲の端の保護**: **−5° / +10°（Engineering の暫定）のまま**（首の芯の扇の端面）。作業中はソフトの制限を **−1°〜+1°**（Engineering の制御）にし、スキッドで頭が床に乗る。**ハード端の −5° / +10° ではすき間が 601 / 2062 mm³ 残る**（`j1_pitch_2026-09-30.md`）。

### (4) 頭の殻の空洞の強度（PLA、E = 3.5 GPa [R]、梁の概算 [C]）

- フードは **PLA の別部品（頭のあごの空洞に接着 / ねじ止め）** とする案。**壁 1.6 mm・屋根 1.6 mm・足の帯 3.6×4 mm [A]**（最小 1.2 以上）。
- **壁**（高さ 15、長さ 34、上端固定・下端自由の片持ち）: **1 N の横向きの力（全体）で下端が 0.028 mm** 動く。**c₀ = 0.1 mm の 1/4 未満**。物（1 円玉 約 2 g）を押す力は 0.01 N 程度なので**壁の変形は無視できる**。
- **口の前の縁（屋根の漏斗の前、幅 60）**: 中央に 0.5 N で **0.063 mm** たわむ（単純支持の梁）。**c₀ と同程度**なので、**指で押すとすき間が変わる**。ただし取り込みの力（0.01〜0.1 N）では 0.006 mm 以下。
- **足の帯**（頭の重さ 2 N を 3.6×190 mm で受けると 0.003 MPa）: 圧縮は無視できる。**問題は強度でなく平らさ**（底面の平面度 ±0.05 を、やすり掛けで作る）。
- **あごの残り壁**: フードを入れるあごの空洞（25 cm³）の周りに **2 mm 以上** を残す案 [A]（あごの実体が中実か殻かは未確認）。**未検証**: あごの外殻の強度、ねじ穴、口の前縁の接着面。

### (5) 頬の下の LED を口の前の外側の角へ移す案の照明の効き（再計算。`tools/light_placement_hood.py`、`results/light_placement_hood_2026-09-30.json`）

点光源 h/r³、頭の影 + フードの壁・屋根・足の帯の遮り、床の帯 330 点（レンズの前 38〜147 mm、横 ±23）。比 = 最も明るい点 / 最も暗い点。

| 斜め照明（頬） | 真っ暗の点 | 照度比 |
|---|---|---|
| ① 現行（X−212、\|y\| 40、Z7）、フードなし | 0/330 | **14.7 倍**（前回の 15 倍） |
| ② 現行位置、**フードあり** | **60/330** | 19.9 倍 |
| **③ 案: 口の前の外側の角（X−236.5、\|y\| 36、Z6）、フードあり** | **0/330** | **35.4 倍** |
| ④ X−234、\|y\| 38、Z6 | 0/330 | 30.3 倍 |
| ⑤ Z4（低め） | 0/330 | 36.0 倍 |
| ⑥ Z9（高め） | 0/330 | 34.1 倍 |

| 通常照明（口の線） | 真っ暗の点 | 照度比 |
|---|---|---|
| ① 現行（X−220、\|y\| 44.7、Z21）、フードなし | 2/330 | **11.2 倍**（前回の 11 倍） |
| ② 現行位置、フードあり | 2/330 | 11.2 倍（**フードの影響なし**。光源の高さ 21 > 屋根 16.6） |
| ③ 口の線の前端（X−232、\|y\| 41、Z21） | 0/330 | 20.9 倍 |

- **斜めの LED を前へ出すと遮りは無くなるが、床の近い点との距離が縮んで明るさのむらが 15 → 35 倍に悪化**（h/r³ は近い側で急に大きくなる）。Engineering の前の結果（照明の較正画像なし: 30〜56 倍で巡回 0.82、較正で 0.93）に近い水準。
- **通常の口の線は現行位置のままでよい**（フードの影響なし）。
- 悪化を抑える案（未検証）: (i) **照明の較正画像**（白いカードで割る。前回 0.93）(ii) **漏斗の壁を透明（クリアの PETG）にして、頬の下の現行位置から光を通す**（遮りが減れば 15〜20 倍に戻る可能性。光の減衰・散乱は未確認）(iii) 斜めの LED を口の前の外側の角に置き、**遠い側用に高い出力の 2 灯目**を同じ位置に足す（電力・発熱）。

## 5. 限界

- 箱の重なり・点光源・梁の概算。**フードはまだ頭に組み込まれていない**（Fusion 切断のため CAD 未変更）。**実物の光・影・接地・ToF の最短距離は未確認**。安全・合格ではない。
- スキッドの形（前端 R6、あごへの接合）と重心は未設計・未確認。

## 6. 次にやること

1. Fusion が戻ったら、§2 の案を `HEAD INTAKE on E3 STUDY` に反映（横のスキッド・後ろのスキッド・ToF・LED の位置、顎板・REF スキッドの除去）。
2. Engineering: c の基準（床から。シミュの定義どおり）、J1 の柔らかい追従と分解能、ToF の最短距離、斜め LED の 35 倍の許容（較正画像）。
3. User: 前 30 mm に床に触れる部品が無い頭の外観（顎板・双子スキッドの形が変わる）を見る。

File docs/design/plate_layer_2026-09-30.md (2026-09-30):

# 背板の層（z ≥ 77）— 案 (a) DRUM-FULL と案 (b) 同心ドームの縁（2026-09-30）

> **【常に先頭に置く注意】現行の CAD（KNUCKLE DRUM のみ）では、まっすぐ（124 mm³）に比べ、曲げた姿勢で 2250〜2939 mm³ のすき間の体積が残る（約 20 倍、18〜24 倍）。** 背板の層（約 1020 mm³/姿勢）は、この文書の案 (a)(b) をまだ採っていないので**現行 CAD では未解決のまま**。J1 ピッチは範囲の確認待ち。数値は CAD_CONCEPT / KINEMATIC_SIM（外形 STL のみ、内部部品・公差・たわみなし）。**安全・合格の語は使わない。** 5.7 N・0.25 N·m は暫定（SAFETY_UNVERIFIED）。

**結果の先頭: 案 (a)(b) のどちらも、J2〜J5 の背板のすき間はほぼ消えた（p1: 1373 → 52 / 71 mm³）。ただし残りの大半は J1（頭のピッチ）で、J1 = −40〜−45° は動作範囲（−5〜+10°）の外の姿勢。**

## 1. 背板の構造（測定 = CAD の bbox）

各関節 j の**背板（サドル）は、関節 j の尾側のリンクの背中に載る 90 mm の円板状の板**（LINK1: J2、LINK2: J3、LINK3: J4、TAIL: J5）。隣どうしのつなぎ目は**リンクの真ん中**（x ≈ 47.5、142.5 …）で、**後端は関節 j を中心とする凸のキャップ（R 約 45.5）、前端は次の板の凹の椀（R 約 48.7）**。板は帯 |y| ≤ w(z) を切ったドーム（半幅 w が z 77 で 41.5、z 88 で 31.5、z 93 で 16.5）。

**胴の層と同じ原因**: キャップは円 R 45.5 を帯 w(z) で切った形（円ではない）。z が上がると w が小さくなり、**椀の壁（R 48.7 の円）が痩せたキャップと向き合う位置ですき間が 5〜10 mm に広がる**。

## 2. 2 案（CAD は別コンポーネント。既存の板は変えていない）

| 案 | 形 | Fusion のコンポーネント | 外観 |
|---|---|---|---|
| **(a) DRUM-FULL** | 各関節に、背板の高さ（z 77〜94）まで**完全な円柱（円板 R 45.5）**を足す | `PLATE VARIANT A DRUM-FULL …`（J3・J4・J5） | **大きく変わる**。ドームの外側に張り出す: z 77 で 4 mm、80 で 6、85 で 10、88 で 14、**93 で 29 mm**。上面は平ら（z 94）。胴の層（KNUCKLE DRUM）との合計の**腹より張り出す量**は、z 8 で 17 mm、14 で 9、20 で 5（胴の層）と、背板で最大 29 mm |
| **(b) 同心ドーム** | キャップを**回転体のドーム r(z) = 板の半幅 w(z)** に削り、相手の板の椀を**回転体 r(z)+4 mm**に合わせて埋める（すき間 4 mm 一定）。**帯の輪郭は変えない** | `PLATE VARIANT B concentric dome caps …`（J2 の椀の埋め、J3・J4・J5） | **今に近い**。板の後端が丸いドームに小さくなる（キャップが 45.5 → 41.5〜16.5 に縮む）。板の色（セージ／クリーム）は 1 色に統合してある（概念の確認用） |

## 3. 同じ検査の数（0.5 mm、危険体積 mm³。J1 = 頭のピッチ、J2〜J5 = 胴・背板）

| 姿勢 | ① 現行 CAD（KNUCKLE DRUM のみ）合計 | うち J1（頭のピッチ）| うち J2〜J5 | ② 案 (a) DRUM-FULL 合計 | うち J2〜J5 | ③ 案 (b) 同心ドーム 合計 | うち J2〜J5 |
|---|---|---|---|---|---|---|---|
| p0 まっすぐ | 124 | 2 | 122 | 58 | 56 | 26 | 24 |
| p1（J1 −40°） | 2558 | 1185 | 1373 | 1237 | 52 | 1256 | 71 |
| p2（p1 の鏡） | 2939 | 1575 | 1364 | 1627 | 52 | 1646 | 71 |
| p3（J1 −45°） | 2250 | 825 | 1425 | 942 | 117 | 928 | 103 |

- p0 の (a) 58 / (b) 26 は、①の 124 より小さい（背板の細い交点も消えた）。
- **(a)(b) の J2〜J5 は、曲げた姿勢でも 52〜117 mm³（(a)）、71〜103（(b)）。まっすぐの J2〜J5（(a) 56 / (b) 24）の 1〜4 倍**。①の 1364〜1425 から 92〜96 % 減。
- **残りの大半は J1**（1185 / 1575 / 825。p1〜p3 の頭の姿勢は J1 = −40 / −40 / −45°）。**動作範囲（−5〜+10°）の外**だが、J1 の系列（`j1_pitch_2026-09-30.md`）のとおり範囲の中でも 0 でない。
- J2 の背板の層: J2 の凸のキャップ（首の側は板が無い）は案に含めていない（J2 の椀の埋めだけ）。J2 の背板のすき間は p1〜p3 で 0〜53 mm³。

## 4. 質量・確認

- (a): 既存の外側に足す体積 J3 19.3 / J4 19.3 / J5 25.7 cm³ ＝ **合計 64.3 cm³、中実 79.8 g / 中空（殻 1.2 mm）上限 42.9 g**。
- (b): 板の体積の変化 J2 +13.4（椀の埋め）/ J3 −2.6 / J4 −2.6 / J5 −15.5 cm³ ＝ **合計 −7.3 cm³（中実 −9 g、軽くなる）**。
- 干渉: (b) は板どうしの重なり 0 mm³（J3・J4・J5）。(a) は円板と相手の板の重なりを Fusion では確認していない（STL の検査では p0〜p3 で新しい干渉の痕跡なし）。
- **(b) の回転体は 1 mm 刻みの階段で近似**している（すき間の誤差 ±0.5 mm）。実際は滑らかな回転面にする。

## 5. 判断（User）

| 選択肢 | 数（J2〜J5、p1） | 外観 | Design の見方 |
|---|---|---|---|
| 現行 CAD（KNUCKLE DRUM のみ） | 1373 | 今のまま | 約 20 倍が残る |
| (a) DRUM-FULL | 52 | 大きく変わる（最大 29 mm 張り出す） | 数は良いが外観の代償が大きい |
| **(b) 同心ドーム** | 71 | 今に近い | **推奨**（数がほぼ同じで外観の変化が小さい。軽くなる） |

**外観の判断は User に返す。** 採るなら、現行の背板のフィーチャを直す作業（既存の体は変えていない）を次にやる。

## 6. 限界

- 外形 STL のみ。**板どうしの実際の嵌合・ケーブル・ドームの内部は入っていない**。J2 の背板は含まない。**まだ現行 CAD ではない**（別コンポーネントの案）。
- 「ほぼ消えた」は、幅 5〜12.5 mm・深さ 8 mm 以上のすき間が消えたこと。**5 mm 未満の細い溝や、指以外の挟み込みは別**。安全・合格ではない。

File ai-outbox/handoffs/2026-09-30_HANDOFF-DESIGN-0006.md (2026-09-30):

# Handoff — Design（2026-09-30 深夜、承認後の試験片）

- **Git**: `agent/design-floor-watch`（Design worktree のみ）。**Fusion**: 元は未変更。Recovery 複製に `KNUCKLE TEST R46/R34`（組立＋印刷の向き）、FW02 intake の複製に `TEST PIECE B1`（組立＋印刷の向き）
- **先頭の注意**: KNUCKLE DRUM 後もまっすぐ比 約 20 倍（18〜24 倍）の体積が残る。背板 約 1020 mm³ は未解決。J1 ピッチは Engineering の回答待ち
- 印刷は User。STL は印刷の向きで出力済み（README に印刷設定・質量）

## 次に Design がやること

1. 背板の層（未解決のまま。User の指示）、J1 ピッチは Engineering の回答が来てから
2. User が試験片を印刷・確認した結果（探針 d5/d12、感触、外観）で KNUCKLE DRUM を見直す
3. 試験片 B の「段差」の解釈を User が確認 → 必要ならリップだけ作り直す
4. 名前のない体の外観（HEAD E2-V v2）、Head Yaw の首

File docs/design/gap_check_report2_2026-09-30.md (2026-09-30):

# SD-01 すき間チェックの続き — FLANK SKIRT STUDY・r の範囲・KNUCKLE DRUM・頭と首（2026-09-30）

> **【常に先頭に置く注意】KNUCKLE DRUM を入れても、まっすぐ（p0: 124 mm³）に比べ、曲げた姿勢では 2250〜2939 mm³ が残る（18〜24 倍。約 20 倍）。** 残りの内訳: 背板の層（z ≥ 77）約 1020 mm³/姿勢（**未解決のまま**）、J1 ピッチ（Engineering の動作範囲の回答待ち）、胴の層 約 340 mm³。**「解決した」ではなく「胴の層でほぼ 90 % 減った」。**

**確度: CAD_CONCEPT の外形（内部部品・公差・たわみなし）に対する STL ボクセル検査（0.5 mm）。スクリーニングであって、EN 71 / ASTM F963 の適合確認ではない。SAFETY_UNVERIFIED。**
前の報告 `gap_check_report_2026-09-30.md`（ENTRY-D-0003）の続き。**前の報告の一部を取り下げる（§0）。**

## 0. 前の報告からの訂正（先に）

- **「胴の脇の V は形の調整では消せない」は誤りだった**（前の §5、ENTRY-D-0003 (2)(3)）。脇の V の長さの式（7.5/tan φ）は Design の幾何の見積もりで、実測と合わなかった。実測の主因は別で、**胴の層（z < 77）では形の直し（§3 KNUCKLE DRUM）で約 90 % 消える**。柔らかいカバーを先に勧めたのは早かった。
- 尾の「刃」は検査ツールの不具合の人工物で、すでに取り下げている（前の §2）。

## 1. 依頼への回答（要約）

| 依頼 | 結果 |
|---|---|
| 1. 脇のカバー概念（FLANK SKIRT STUDY）。すべる重ね鱗／フラップ優先 | 概念 CAD を作った（`FLANK SKIRT STUDY 01`、J3〜J5 の両脇、静止形の参照）。運動学モデル（帯を A の外形に沿ってぴんと張る、伸縮する想定）で調べたが、**すき間は減らず、増えた**（§2）。**このモデルの範囲では採用しない。** 完全な 3D のカバー（上下の閉じ・背板の層）を設計しないと評価できない |
| 2. 同じ検査で、まっすぐ + 6 姿勢。あご・首の前（J1 −22/−45°）も | 胴の姿勢は p0〜p3（p4・p5 は胴がまっすぐで頭だけ違うので J1 の系列に含めた）。J1 ピッチは **−45/−22/−10/−5/0/+10/+22°**（§4）。前回の 6 姿勢に加え、J1 の系列を足した |
| 3. 幅 5〜12 mm を通る r の範囲を、関節・姿勢ごとに | §2 の表（カバーなし）と §3 の表（KNUCKLE DRUM 後）。**J3〜J5 は r = 42.5〜50 mm（5〜95 % で 44.4〜49.8）の輪**。J2 は r = 28〜49（30.5〜38）。J1 はピッチと向きで変わる（§4） |
| 4. 頭と首の下の後ろの材料、あごの後ろ端 | 下の後ろの材料: **172 → 2 mm³**（CAD 済み）。あごの後ろ端（J1 ピッチ）: 幾何では直せず、カバーが要る（§4）。あごのフラップは効かなかった |
| 5. 外形 STL のみの検査の限界 | §6 に今のまま残した（＋今回の限界を追記） |

## 2. r の範囲（カバーなし・現状。Engineering へ）

幅 5〜12.5 mm・深さ 8 mm 以上・外から届く、の体積。r = 関節の軸（J2 −95、J3 0、J4 95、J5 190。J1 は (−181.8, 32.4) の XZ）からの水平（J1 は側面）の距離。箱は節の真ん中で区切る。

| 姿勢 | 関節 | 体積 mm³ | r の範囲 mm（5〜95%） | 幅 mm | 高さ z mm | うち z<77（胴）mm³ |
|---|---|---|---|---|---|---|
| p0 まっすぐ | J1 | 2 | 43.4〜43.9（43.4〜43.9） | 5.2〜6.4 | 47.2〜76.2 | 2 |
| p0 まっすぐ | J2 | 4 | 35.7〜36.4（35.7〜36.3） | 5.2〜5.2 | 75.2〜75.2 | 4 |
| p0 まっすぐ | J3 | 8 | 47.2〜48.4（47.3〜48.3） | 5.2〜5.2 | 75.2〜76.8 | 8 |
| p0 まっすぐ | J4 | 21 | 47.0〜48.4（47.0〜48.3） | 5.2〜5.2 | 75.2〜76.8 | 21 |
| p0 まっすぐ | J5 | 109 | 45.5〜48.7（45.6〜48.5） | 5.2〜10.4 | 75.2〜77.8 | 43 |
| p1 J3+50 J4−50 J5+50 | J1 | 1185 | 3.7〜32.4（6.5〜22.7） | 5.0〜9.2 | 20.8〜47.8 | 1185 |
| p1 J3+50 J4−50 J5+50 | J2 | 1828 | 27.9〜49.1（30.5〜37.9） | 5.0〜10.6 | 13.2〜87.8 | 1774 |
| p1 J3+50 J4−50 J5+50 | J3 | 728 | 43.1〜50.0（44.7〜49.6） | 5.0〜9.5 | 13.2〜86.2 | 452 |
| p1 J3+50 J4−50 J5+50 | J4 | 1741 | 42.6〜50.0（44.5〜49.6） | 5.0〜9.9 | 11.2〜85.8 | 1338 |
| p1 J3+50 J4−50 J5+50 | J5 | 1325 | 42.5〜50.0（44.4〜49.8） | 5.0〜10.6 | 11.8〜85.2 | 1019 |
| p2 p1 の鏡 | J1 | 1575 | 8.2〜44.9（10.6〜22.4） | 5.0〜7.8 | 15.8〜73.2 | 1575 |
| p2 p1 の鏡 | J2 | 1816 | 27.9〜49.1（30.5〜37.9） | 5.0〜10.6 | 13.2〜87.8 | 1762 |
| p2 p1 の鏡 | J3 | 728 | 43.1〜50.0（44.7〜49.6） | 5.0〜9.5 | 13.2〜86.2 | 453 |
| p2 p1 の鏡 | J4 | 1729 | 42.6〜50.0（44.4〜49.6） | 5.0〜9.9 | 11.2〜85.8 | 1337 |
| p2 p1 の鏡 | J5 | 1328 | 42.5〜50.0（44.4〜49.8） | 5.0〜10.6 | 11.8〜85.2 | 1019 |
| p3 J3+50 J4+50 J5+50 | J1 | 825 | 3.7〜32.4（5.8〜27.1） | 5.0〜9.2 | 22.2〜47.8 | 825 |
| p3 J3+50 J4+50 J5+50 | J2 | 1828 | 27.9〜49.1（30.5〜37.9） | 5.0〜10.6 | 13.2〜87.8 | 1774 |
| p3 J3+50 J4+50 J5+50 | J3 | 727 | 43.1〜50.0（44.7〜49.6） | 5.0〜9.5 | 13.2〜86.2 | 452 |
| p3 J3+50 J4+50 J5+50 | J4 | 1718 | 42.6〜50.0（44.4〜49.6） | 5.0〜9.9 | 11.2〜86.2 | 1330 |
| p3 J3+50 J4+50 J5+50 | J5 | 1394 | 42.6〜50.0（44.4〜49.6） | 5.0〜10.6 | 11.8〜85.2 | 1087 |

- **J3〜J5 の r は 42.5〜50 mm の輪に集まる**（玉 R 45.5〜46 と椀の内側 R 49.5 の間 ± 数 mm）。脇の面（半径 46 mm 付近だが外側の r > 52）には出ない。前の「脇の V」の見積もりと違い、**同心のすき間（4 mm）そのものが、下の方（z 11〜35）と背板（z ≥ 77）で 5〜10 mm に広がっている**のが実態（§3）。
- z < 77（胴）の割合は J3 で 62 %、J4 で 77 %、J5 で 77 %（p1）。残りは背板の層。
- J2 は r が小さい（30〜38）: 首の玉が R 34 と細く、椀の縁が近い。

## 3. 原因と直し: KNUCKLE DRUM（形の調整。胴の層でほぼ解決）

**原因**: 同心ナックルの「4 mm 一定」は、玉が**完全な円柱 R 46** の高さ（z 30〜70）だけで成り立つ。玉の脇は樽形の絞り（`W(z)`: z 14 で半幅 37、z 8 で 29、背板の z 88 で 31）で痩せるが、椀の内壁は R 49.5 の円柱のまま。**曲げると椀の縁の角度（39°）＋回転（50°）= 89° が、玉が痩せ始める角度（z 14 で 54°）を越え、椀が痩せた玉の面と向き合って、すき間が 5〜10 mm に広がる**。まっすぐでは椀が痩せた所まで届かないので出ない。

**直し**: 各関節の玉の脇を、**z 8〜76 で完全な円柱 R 46（首の J2 は R 34）に戻す**（Fusion: `KNUCKLE DRUM J3/J4/J5`（LINK1/2/3 の中）、`J2`（NECK-V の中）、アイボリー）。胴の樽形の脇の絞りが、関節の玉の所だけ円柱の肩として出る。

**結果**（0.5 mm、KNUCKLE DRUM のみ。カバーなし ① との比較）:

| 姿勢 | ① カバーなし（現状） | ② 脇のフラップ（J3〜J5） | ③ 膝の円柱 J2〜J5（KNUCKLE DRUM） | ③ のうち z<77（胴）| ③ のうち z≥77（背板）|
|---|---|---|---|---|---|
| p0 まっすぐ | 144 | 7295 | **124** | 58 | 66 |
| p1 J3+50 J4−50 J5+50 | 6807 | 11284 | **2558** | 1529 | 1029 |
| p2 p1 の鏡 | 7176 | 11624 | **2939** | 1918 | 1021 |
| p3 J3+50 J4+50 J5+50 | 6492 | 11917 | **2250** | 1231 | 1019 |

J1 の列: 頭のピッチの塊（§4）。残りの内訳（KNUCKLE DRUM 後）:

| 姿勢 | 関節 | 体積 mm³ | r の範囲 mm（5〜95%） | 幅 mm | 高さ z mm | うち z<77（胴）mm³ |
|---|---|---|---|---|---|---|
| p0 まっすぐ | J1 | 2 | 43.4〜43.9（43.4〜43.9） | 5.2〜6.4 | 47.2〜76.2 | 2 |
| p0 まっすぐ | J2 | 4 | 35.7〜36.4（35.7〜36.3） | 5.2〜5.2 | 75.2〜75.2 | 4 |
| p0 まっすぐ | J3 | 6 | 47.2〜48.4（47.3〜48.3） | 5.2〜5.2 | 75.2〜76.8 | 6 |
| p0 まっすぐ | J4 | 19 | 47.0〜48.4（47.0〜48.3） | 5.2〜5.2 | 75.2〜76.8 | 19 |
| p0 まっすぐ | J5 | 93 | 46.0〜48.7（46.0〜48.5） | 5.2〜6.9 | 75.2〜77.8 | 27 |
| p1 J3+50 J4−50 J5+50 | J1 | 1185 | 3.7〜32.4（6.5〜22.7） | 5.0〜9.2 | 20.8〜47.8 | 1185 |
| p1 J3+50 J4−50 J5+50 | J2 | 53 | 36.4〜49.1（45.9〜48.9） | 5.0〜7.1 | 75.2〜87.8 | 0 |
| p1 J3+50 J4−50 J5+50 | J3 | 319 | 43.1〜49.5（44.7〜49.2） | 5.0〜9.5 | 75.2〜86.2 | 44 |
| p1 J3+50 J4−50 J5+50 | J4 | 568 | 43.1〜49.5（44.5〜49.2） | 5.0〜9.9 | 15.8〜85.8 | 167 |
| p1 J3+50 J4−50 J5+50 | J5 | 433 | 43.5〜49.5（44.7〜49.1） | 5.0〜10.6 | 70.8〜85.2 | 133 |
| p2 p1 の鏡 | J1 | 1575 | 8.2〜44.9（10.6〜22.4） | 5.0〜7.8 | 15.8〜73.2 | 1575 |
| p2 p1 の鏡 | J2 | 53 | 36.4〜49.1（45.9〜48.9） | 5.0〜7.1 | 75.2〜87.8 | 0 |
| p2 p1 の鏡 | J3 | 319 | 43.1〜49.5（44.7〜49.2） | 5.0〜9.5 | 75.2〜86.2 | 44 |
| p2 p1 の鏡 | J4 | 556 | 43.1〜49.5（44.4〜49.1） | 5.0〜9.9 | 15.8〜85.8 | 166 |
| p2 p1 の鏡 | J5 | 436 | 43.5〜49.5（44.7〜49.1） | 5.0〜10.6 | 12.8〜85.2 | 133 |
| p3 J3+50 J4+50 J5+50 | J1 | 825 | 3.7〜32.4（5.8〜27.1） | 5.0〜9.2 | 22.2〜47.8 | 825 |
| p3 J3+50 J4+50 J5+50 | J2 | 53 | 36.4〜49.1（45.9〜48.9） | 5.0〜7.1 | 75.2〜87.8 | 0 |
| p3 J3+50 J4+50 J5+50 | J3 | 319 | 43.1〜49.5（44.7〜49.2） | 5.0〜9.5 | 75.2〜86.2 | 44 |
| p3 J3+50 J4+50 J5+50 | J4 | 550 | 43.1〜49.5（44.4〜49.1） | 5.0〜9.9 | 15.8〜86.2 | 163 |
| p3 J3+50 J4+50 J5+50 | J5 | 503 | 43.1〜49.5（44.6〜49.1） | 5.0〜10.4 | 14.8〜85.2 | 199 |

- 干渉: 円柱と椀側のリンクの重なり **0 mm³**（p0・p1・p3。p2 は鏡）。KNUCKLE DRUM が既存の形の外側に足す体積は **1 つあたり 11〜13 cm³**（J3 11.5、J4・J5 13.4。J2 は未計算。円柱そのものは 289 cm³ だが、ほとんどは既存の胴の中）。中実の PLA で約 15 g / 個。**質量は Engineering の質量表に足す必要がある**（実際は外殻なので、これより軽い）。
- **外観が変わる**: 各関節の玉の脇が円柱の肩として、下の樽形の腹より 5〜10 mm 張り出す（`assets/gap_drum_before_after.png`）。「蛇の胴の連続した樽」から「つなぎ目に膝がある」見た目になる。**人の評価が要る**（HUMAN_EVALUATED = 0）。
- 残り: **背板の層（z ≥ 77）が 1 姿勢あたり約 1020 mm³**（J3 x 36〜66・J4 x 124〜162・J5 の弧の端）。背板は丸いドーム（半幅が z 77 で 41、z 93 で 16）で、円柱にすると平らな円盤になり形が別物になるので、KNUCKLE DRUM の対象にしていない。**背板のすき間は未解決**。

## 4. 頭と首（J1 ピッチ）

- **下の後ろの三日月（p0）**: 頭の下の後ろに埋め物を足した（Fusion: `E2-V lower-rear fill`、y ±18、首から 2.6 mm 離す）。**p0 の危険体積 172 → 2 mm³**。（最初の埋め物（4 mm 離す）は 262 mm³ と悪化したので 2.6 mm 版に置き換えた。）
- **J1 ピッチの系列**（埋め物あり、KNUCKLE DRUM は関係なし）:

| J1 ピッチ | 危険体積 mm³ | r の範囲 mm（5–95%） | 軸まわりの角 | 幅 mm | y mm | z mm |
|---|---|---|---|---|---|---|
| -45° | 856 | 5.5〜44.5（6.7〜32.6） | -75°〜45° | 5.0〜9.0 | -23.2〜23.2 | 22.8〜63.8 |
| -22° | 1228 | 10.4〜43.7（14.3〜18.7） | -52°〜22° | 5.2〜7.8 | -22.2〜22.2 | 17.8〜47.2 |
| -10° | 1562 | 23.9〜43.8（24.4〜34.1） | -44°〜79° | 5.0〜10.0 | -21.8〜21.8 | 9.8〜75.2 |
| -5° | 601 | 25.4〜43.8（25.9〜34.2） | -40°〜84° | 5.0〜7.0 | -21.8〜21.8 | 12.2〜75.8 |
| +0° | 2 | — | — | — | — | — |
| +10° | 2062 | 43.2〜51.9（45.5〜51.3） | 15°〜99° | 5.0〜11.3 | -25.8〜25.8 | 45.2〜75.8 |
| +22° | 4307 | 45.0〜52.0（45.6〜51.7） | 15°〜37° | 5.0〜9.5 | -25.8〜25.8 | 45.2〜63.8 |

- **ピッチを少しでも動かすと、あご・首の前（下げる側）と、フード・襟（上げる側）にすき間が出る**。0° だけ 2 mm³。−5° でもう 601 mm³。**下げる側**: r = 24〜44 → 10〜44 → 5〜44 mm（角度が大きいほど小さい r）。**上げる側**: r = 43〜52 mm（VISOR のフード R 46〜48 と逃げ輪 R 52 の輪）、+22° で 4307 mm³。
- 原因: 頭のあごの塊と首のピボットの穴の**端面が軸から出る放射状の平面**で、回すと端面の間が V に開く。同心にできない（端面は軸から放射する）。**幾何だけでは消せない**（これは本当）。
- **あごのフラップ**（頭の下の後ろの角から首の腹の先へ張る帯、`chin_flap_mesh`）: p5・p4 で**効かなかった**（p4 は 856 → 1104 に悪化）。すき間は、あごの塊の後ろの穴（首の舌の下、y ±30、z 8〜22）の**幅全体**で開いており、帯（y ±24）が幅足りず、横から入れる。幅を広げても、側面の壁が要る。**評価できていない**。
- 提案: J1 ピッチの範囲を Engineering と決める（±5° に絞っても 601 mm³ 出るので、範囲を絞るだけでは足りない。0° 固定なら 2 mm³）。または頭の後ろの穴全体を覆う**箱形のカバー**（頭側の後ろの壁）を設計する。

## 5. FLANK SKIRT STUDY（脇のフラップ）の記録

- **概念**: 各関節の各脇に、椀側リンクの角に根元を固定した薄い帯（TPU 想定、厚さ 1.2 mm）を付け、玉側リンクの外形の上をすべらせる。帯は A の外形（玉の円 ∩ 樽形）に沿ってぴんと張り、先端は A に触れて閉じた空洞にする。運動学モデル `tools/flank_skirt.py`（帯の長さは接点 ＋ 8 mm、伸縮する想定。TPU の伸び 1.75〜3 倍は**未検証**）。
- **CAD**: `FLANK SKIRT STUDY 01 - DESIGN CONCEPT - NOT PARTS`（Fusion、J3〜J5 の両脇、樽形の断面 z 2〜93、x は軸 −8〜+65.5、厚さ 1.2、脇から 0.8 mm 浮かせ）。**静止形の参照。運動は Fusion では再現していない。**
- **結果**: **すき間は減らず増えた**（§3 の表 ②: p1 で 6807 → 11284）。原因: (a) 帯は脇の側面だけを塞ぐ**縦の壁**で、上下が開いたまま。閉じた空洞のつもりの所が、幅 5〜10 mm の**上下が開いた深いスリット**になった、(b) 背板の層（z ≥ 77）の V は帯の外、(c) J5 の尾の外形のモデルが粗く、J5 だけ 7000 mm³ 台に悪化（モデルの誤りで、概念の評価に使えない）、(d) 玉が痩せる低い z で帯と体の間が空く。
- **判断**: このモデルでは採らない。柔らかいカバーが必要なら、**上下（腹の側・背板の上）まで閉じる 3D の形（袖状）**が要り、これは別の設計（未着手）。KNUCKLE DRUM で胴の層が解決するので、優先度は下がった。
- 唇（椀の縁の角から玉の面へ触れる薄い帯、`wiper_meshes`/`lip_meshes`）も試した: 椀の縁の向こうの低い z のすき間が残り、効かなかった（J4: 1228 → 964〜857、J3 は 728 → 778〜834）。原因は同じ（玉の脇が痩せて円柱でない）で、KNUCKLE DRUM が根本の直し。

## 6. 検査の限界（今のまま残す ＋ 今回の追加）

- 外形のみ。内部の部品・ケーブル・ネジ頭・公差・たわみ・柔らかい物の変形は入っていない。
- 幅 5〜12 mm・深さ 8 mm はスクリーニングの基準で、指の先端の寸法・角度・押す力そのものではない（子どもの指・手首の分布は Engineering の `child_anthropometry`）。0.5 mm の格子で 5.0 mm ちょうどのすき間は判定が揺れる。
- 手首・首が入る大きい開口（閉じ込め）はこの検査では見ていない。姿勢は有限個。全角度の連続ではない。
- **追加**: (1) 柔らかい物（フラップ・蛇腹）は剛体の三角形として置いただけで、変形・摩擦・つっぱりは入っていない。伸縮の量は仮定。(2) **箱の境界が閉じた空洞を切ると、空洞が外につながって見える**（人工物）。箱は節の真ん中で区切った。(3) 関節の帰属（J1〜J5）は、すき間の位置から最も近い軸に割り当てた近似で、境目の塊は隣に入ることがある。(4) 背板・首の層の A／B の役割は測定・確認が足りない（背板はドームで、椀・玉の対応が胴と違う可能性）。(5) KNUCKLE DRUM の後の胴の外形が、他の検討（VISOR のフード、ケーブル空き、質量）に与える影響は未確認。

## 7. ファイル

- ツール: `tools/gap_check.py`、`gap_radial.py`（r の範囲）、`gap_pitch.py`（J1 の系列）、`flank_skirt.py`（フラップ・唇・玉の円柱・あごのフラップのモデル）、`gap_skirt_run.py`
- 結果: `results/gap_rad_v3_base_p*.json`（① カバーなし）、`gap_rad_v3_skirt_p*.json`（② フラップ）、`gap_rad_v5_drum_p*.json`（③ KNUCKLE DRUM ＋ J2）、`gap_pitch_v3.json`（J1 の系列）
- 図: `assets/gap_drum_before_after.png`
- Fusion: Recovery 複製に保存（`E2-V lower-rear fill`、`KNUCKLE DRUM J2〜J5`、`FLANK SKIRT STUDY 01`）。元は未変更

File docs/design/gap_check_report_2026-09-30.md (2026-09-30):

# SD-01 すき間チェック（ENTRY-E-0003 (5) への回答）— 2026-09-30

> **【常に先頭に置く注意】KNUCKLE DRUM を入れても、まっすぐ（p0: 124 mm³）に比べ、曲げた姿勢では 2250〜2939 mm³ が残る（18〜24 倍。約 20 倍）。** 残りの内訳: 背板の層（z ≥ 77）約 1020 mm³/姿勢（**未解決のまま**）、J1 ピッチ（Engineering の動作範囲の回答待ち）、胴の層 約 340 mm³。**「解決した」ではなく「胴の層でほぼ 90 % 減った」。**

> **2026-09-30 追記: §1(2)〜(4)、§5、§6 の「脇の V は形では消せない」「柔らかいカバーを推奨」は続報 `gap_check_report2_2026-09-30.md` で訂正した。胴の層は KNUCKLE DRUM（形の直し）でほぼ解決する。**

**確度: CAD_CONCEPT の外形（内部部品・公差・ケーブルなし）に対する STL ボクセル検査。スクリーニングであって、EN 71 / ASTM F963 の適合確認ではない。SAFETY_UNVERIFIED。**

Engineering の要求: 「人が触れる範囲・全角度で **5〜12 mm の隙間を作らない**（首・手首が入る閉じた開口を作らない、C 字の口を袋小路にしない、外れる小部品を 31.7 mm の筒に入れない）」。

## 1. 結論（先に）

1. **静止（まっすぐ, p0）**: 検査で見つけた実欠陥 5 件を CAD で直した（§3）。残りは 3 か所・合計 約 740 mm³（§4）: 頭と首の下の後ろ 170、J4 と J5 の背板の継ぎ目と脇の V の接点 264 + 260、ほか 6。
2. **曲げた姿勢（p1〜p3）では「全角度で 5〜12 mm の隙間なし」は成り立たない。** 同心ナックルの 4 mm 一定は**ナックルの円弧の中だけ**で、**胴の脇（フランク）に V 字のくさびができ、その中で幅が 5〜12 mm を通る**（J2・J3・J4・J5 の全部の関節で出る。合計 6500〜6900 mm³、まっすぐの約 9 倍）。形の調整では消せない（§5）。Engineering の「Design の 4 mm 一定のすき間は 5 mm 未満なので規則を満たす」は、**静止姿勢のナックルの弧についてだけ正しい**。
3. **頭を下げると（J1 ピッチ −22°、−45°）、あごと首の前の間にも 5〜9 mm のくさびが出る**（856〜1228 mm³、はさみ型）。胴はまっすぐでも起きる。
4. したがって規則は「**幾何だけで守る**」では足りず、脇の V とあごのくさびを **(a) 柔らかいカバーで塞ぐ** か **(b) 閉じる力をしきい値以下にする**（トルクリミッターの窓と接触点の半径から）か、のどちらかが要る。Design は (a) を次に検討する（§6）。

## 2. 方法と限界

- Fusion の Recovery 複製から**部品ごとに STL を書き出し**、姿勢ごとの 4×4 変換を Python で掛ける（`docs/design/tools/gap_check.py`、numpy のみ）。姿勢: p0 まっすぐ / p1 J3+50 J4−50 J5+50 J2V+50 J1V−40 / p2 その鏡 / p3 全部 +50・J1V−45 / p4 J1V−45 / p5 J1V−22。
- 占有はボクセル（0.5 mm）。**「すき間」= 空きのうち、13 方向の局所幅が 5〜12.5 mm で、外から届き、開いた空間から 8 mm 以上奥にある所**。幅が 5 mm 未満の細い溝は探針が入らないので数えない。
- 限界:
  - 外形のみ。内部の部品・ケーブル・ネジ頭・公差・たわみ・柔らかい物の変形は入っていない。
  - 幅 5〜12 mm・深さ 8 mm はスクリーニングの基準で、指の先端の寸法・角度・押す力そのものではない（子どもの指・手首の分布は Engineering の `child_anthropometry`）。
  - 0.5 mm の格子で 5.0 mm ちょうどのすき間は判定が揺れる（幅 5.0 が多いのはこのため）。
  - 幅 5〜12 mm の帯を通る**閉じ込め・つぶれの大きさ**（手首・首が入る大きい開口）はこの検査では見ていない。
  - 姿勢は 6 つだけ。全角度の連続ではない。
- **検査ツール自体の不具合を 1 つ直した（2026-09-30）**: 箱の x の始点が固体の端より右にあると、その固体の行が全部埋まる（負の添字のスライス）。**この不具合のある版で出した「尾の端に厚さ 1.6 mm の刃とくさび」は不具合の人工物で、実在しなかった**（Fusion で尾の帯を切り落としたが、直した検査で前後が同一と分かり、フィーチャを削除して元に戻した）。**この報告の数字はすべて直した版で取り直したもの**（`results/gap_crev_v2_*.json`）。不具合のある版の結果ファイルは削除した。

## 3. 直したもの（p0 で見つけて CAD を変更。直す前の数字は不具合のある版を含む場合があり、以下は「直した内容」のみ）

| # | 場所 | 見つけたもの | 直し |
|---|---|---|---|
| 1 | 背板どうし（J3〜J5） | フラット背板の継ぎ目に**尖り**（5.0 mm ちょうどのすき間） | 凹の同心円弧の背板（軸まわりで 4 mm 一定、縁は flush） |
| 2 | 首 VISOR 頭巾 | 頭巾と芯の間に**放射状の溝 10 mm** | 頭巾を r46〜48（2 mm）、逃げ輪を r52 に |
| 3 | 首 VISOR ポケット | ポケット **8 mm** | 芯 r45 / ポケット r45〜49（4 mm）/ 襟 r49+ |
| 4 | J2 の板 | 板が低くケーブルの空きが 3 mm | サドル形（上面 Z96、軸の上 約 19 mm、後ろの凹弧は J3 と同心）。J2 の板は p0〜p5 で 6 mm³ 以下 |
| 5 | 頭と首 | 頭の下の後ろと首の間の三日月（頭の後ろの下の縁が r32 の首の縁より外に出る） | 頭の下の後ろの縁（r32）を削った。頭側に埋める材料が足りず、まだ 170 mm³ 残る（§4） |

## 4. 残っているもの（静止 p0、0.5 mm、直した版）

| 場所 | 体積 | 位置 (mm) | 幅 | 中身 | 扱い |
|---|---|---|---|---|---|
| 頭と首の下の後ろ | 170 mm³ | x −160〜−155、|y|≤16、z 16〜18 | 5.5〜7.0 | 首の r32 の縁に対して頭側の材料が足りず、下の後ろに小さい開き（`assets/gap_head_neck_residual.png`） | **未修正**。頭に同心の縁（r32）の材料を足す。頭の外形を変えるので、次の Fusion 作業で |
| J4 の背板の継ぎ目 | 2×122 mm³ | x 132〜150、|y| 9〜31、z 75〜84 | 5.2〜9.9 | J4 の 4 mm の同心弧が脇で**下の層だけ V に広がる**（z 65 の断面で入口が 約 25 mm 幅、`assets/gap_j4j5_top.png`）。弧と水平の 2〜3 mm のスリットの交点の局所幅が 5 mm を超えて出る | 未修正。脇の V（§5）と同じ種類として扱う |
| J5 の背板の継ぎ目 | 260 mm³ | x 140〜160、|y|≤37、z 75〜78 | 5.2〜8.7 | 同上（J5 側、水平スリットの交点） | 同上 |

- 尾の先・J2〜J3 の間・J3〜J4 の間: ほぼ 0（6 mm³ 以下）。断面 `assets/gap_tail_sections.png`（「直す前・直した後」は同一）

## 5. 曲げた姿勢: 胴の脇の V（未解決・最重要）

同心ナックルは、玉（凸）と椀（凹）の間を軸のまわりで 4 mm 一定に保つ。しかし胴の脇の面は直線で、玉から出る所で接線になる。曲げると、隣の節の脇の面が**角度 φ で開く**ので、脇に V ができる。

- V の幅 ≈ 4 mm + s·tan φ（s は接線点から脇に沿った距離）。**5〜12.5 mm を通る長さ ≈ 7.5 / tan φ**。φ が 43° 以下なら 8 mm を超える（φ = 25° で 16 mm、10° で 42 mm）。つまり**小さい角度ほど悪い**。（Design の幾何の見積もり。数値検査は下の表）
- 曲げの内側は、端面の面取りが 52° で干渉しないようにしてあるので、面取りとの差 (52° − φ) の V ができる。φ が 9° 〜 52° の間は 8 mm 以上の長さで 5〜12 mm を通る（見積もり）。
- 検査結果（p1〜p3、0.5 mm）: 関節ごとの大きい塊（J2〜J3: x −38〜−4、J3: x 35〜66、J4: x 94〜126、J5: x 190〜206。幅 5.0〜10.6、深さ 12〜30 mm）。図 `docs/design/assets/gap_p1_top.png`。
- **形の調整では消せない**。脇の壁を椀の外側まで伸ばしても、壁の端で同じ形の V が別の場所にできる（端の幅 = 4 + ℓ·tan φ）。V の幅が「5 未満 → 12.5 超」に**跳ぶ**ことができる形（階段）は、脇の直線と円の接線関係では作れない。
- **頭を下げた時のあごと首の前のくさび**（p4・p5）: あご（頭の下前）と首の間に、ピッチを下げるほどはさみ型に狭まる V ができる（x −180〜−165、z 18〜29、幅 5.2〜8.5、深さ 15〜30 mm）。J1 の動作範囲の設計（ピッチの下限）とあごの形（顎板のそりの後ろ端）で変わる。
- 関節の閉じる力: Engineering の値（0.45 N·m で節の中点 9.5 N、暫定しきい値 手 5.7 N）から、脇（半径 約 46 mm）で 5.7 N を超えないトルクは 5.7 × 0.046 = **0.26 N·m**（首 5.0 N なら 0.23 N·m）。トルクリミッターの窓 0.7〜1.0 N·m とは食い違う。**この算術は Engineering の確認が要る**（接触点の半径・指が入る位置の仮定）。

## 6. 提案（Design 側の次）

- **A. 脇の柔らかいカバー（推奨）**: 各関節の脇に TPU（60A 程度）の蛇腹または重ね鱗を付け、V を外から塞ぐ。硬い部品は同心ナックルのまま。概念の CAD（`FLANK SKIRT STUDY`）を次に作る。**蛇腹の中に入る指の挟み込みは未検証。**
- **B. 力で守る**: 接触点の半径と閉じるトルクから、脇の V で 5.7 N 以下にする（リミッターの窓の見直し。Engineering / User）。
- **C. 角度を狭くする**: V の長さは小さい角度ほど長い。範囲を狭めても V は消えない。**採らない**。
- **D. 形を丸くする（円盤の連なり）**: 脇も円弧にして脇の直線を無くすと V が円弧の隙間になる。ナックルの形が別物（コイン状）になり、外形と接地面が変わる。検討候補としてのみ残す。
- **あご**: J1 のピッチ下限と、顎板の後ろ端を首の前に近づける／首の前に薄いカバーを付ける案を FLANK SKIRT STUDY と一緒に検討する。
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

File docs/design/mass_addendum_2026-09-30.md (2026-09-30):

# 質量の追記（KNUCKLE DRUM ほか、2026-09-30）— 中実（最大値）と中空の 2 通り

> Design は Engineering の設定（`config/robot.yaml` の `mass_budget_g`、`mass_total_g_max` 1700）を**変えない**。下の値を、Engineering の質量表へ**記入してもらう**ための一覧（ENTRY-D-0005）。由来: **[C]** = CAD（STL のボクセル 0.5 mm）から計算、**[A]** = 仮定、**[R]** = 一般値。

> **先頭の注意**: KNUCKLE DRUM を入れても、まっすぐに比べ曲げた姿勢で約 20 倍（18〜24 倍）の体積のすき間が残る（背板 約 1020 mm³/姿勢は未解決、J1 ピッチは回答待ち）。
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

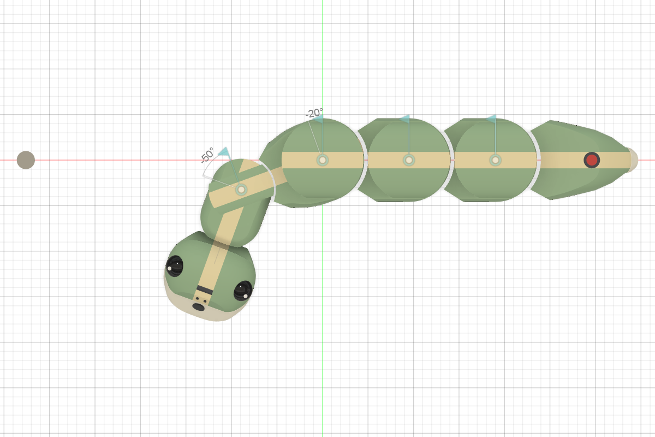
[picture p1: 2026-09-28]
docs/design/renders/eval/EVAL_SD01E_child_near_top.png

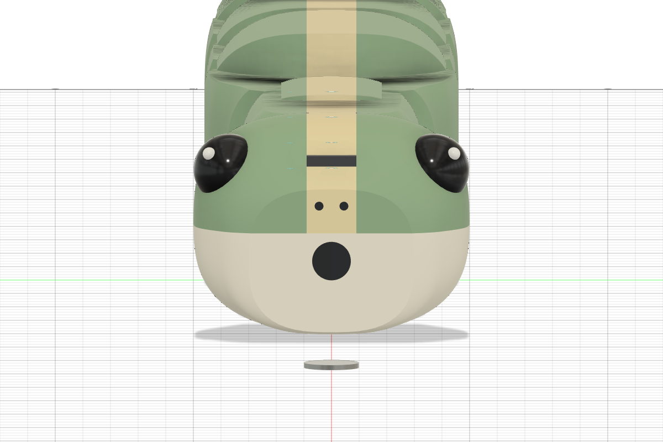
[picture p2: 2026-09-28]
docs/design/renders/eval/EVAL_SD01E_discovery_face.png

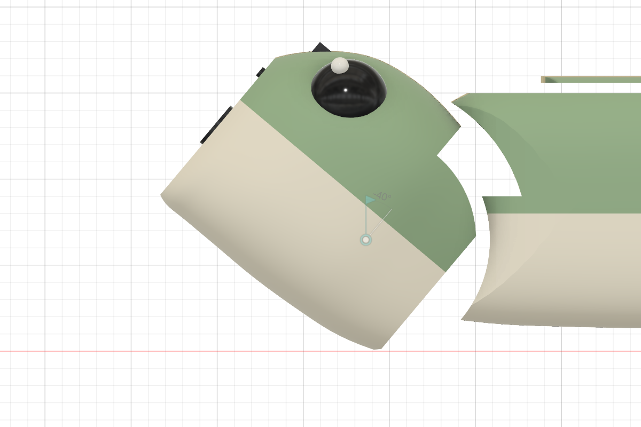
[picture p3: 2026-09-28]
docs/design/renders/SD01R_head_J1_up40_side.png

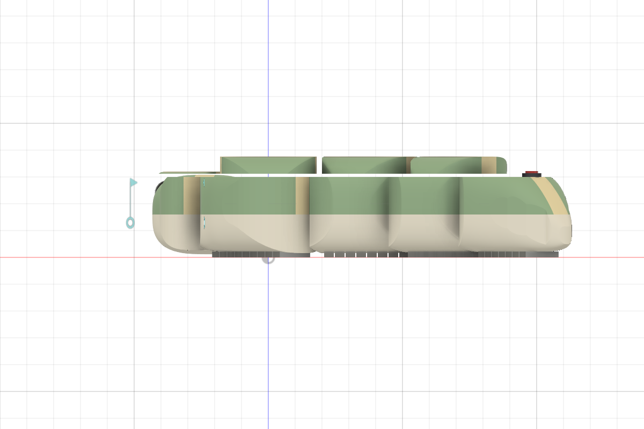
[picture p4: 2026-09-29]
docs/design/renders/eval/EVAL_SD01A_charging145_side.png

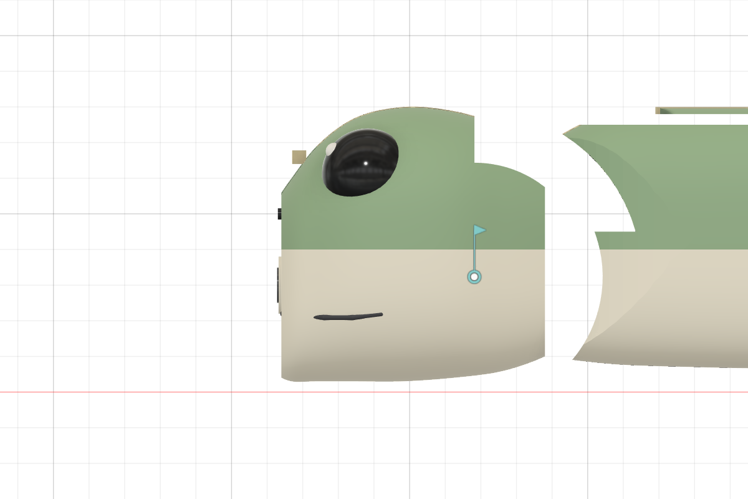
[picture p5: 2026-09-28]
docs/design/renders/eval/SD01E3_head_side_closeup.png

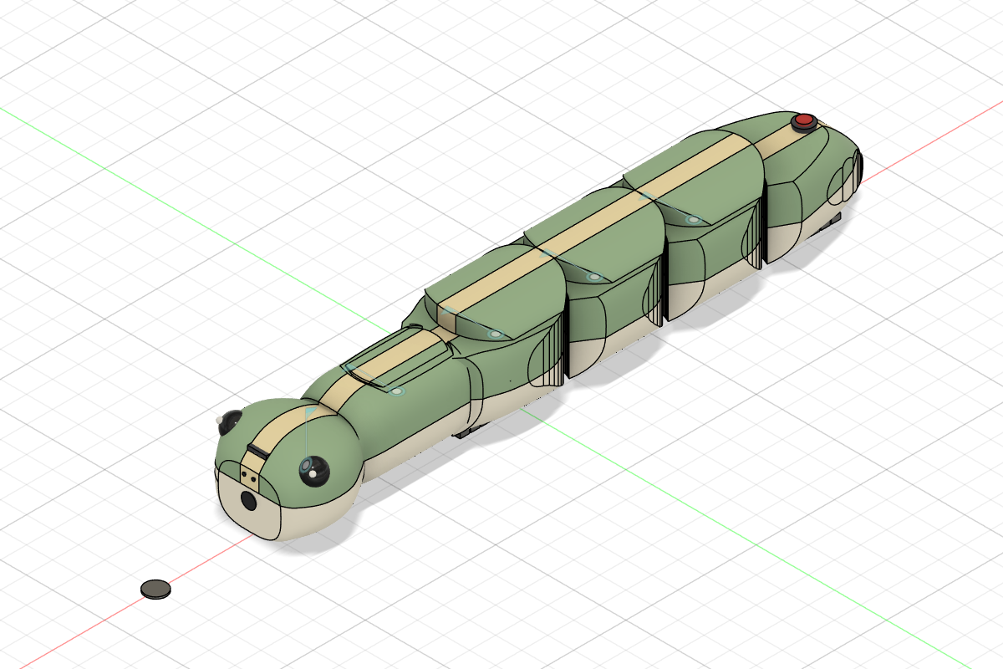
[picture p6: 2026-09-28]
docs/design/renders/SD01R_flush_straight_iso.png

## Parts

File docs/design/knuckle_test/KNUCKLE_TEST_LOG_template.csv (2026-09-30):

piece | angle_deg | location | d5_enters | d12_enters | gap_mm | gap_5_to_12 | note
R46 | 0 | upper
R46 | 0 | middle
R46 | 0 | lower
R46 | 25 | upper
R46 | 25 | middle
R46 | 25 | lower
R46 | -25 | upper
R46 | -25 | middle
R46 | -25 | lower
R46 | 50 | upper
R46 | 50 | middle
R46 | 50 | lower
R46 | -50 | upper
R46 | -50 | middle
R46 | -50 | lower
R34 | 0 | upper
R34 | 0 | middle
R34 | 0 | lower
R34 | 25 | upper
R34 | 25 | middle
R34 | 25 | lower
R34 | -25 | upper
R34 | -25 | middle
R34 | -25 | lower
R34 | 50 | upper
R34 | 50 | middle
R34 | 50 | lower
R34 | -50 | upper
R34 | -50 | middle
R34 | -50 | lower

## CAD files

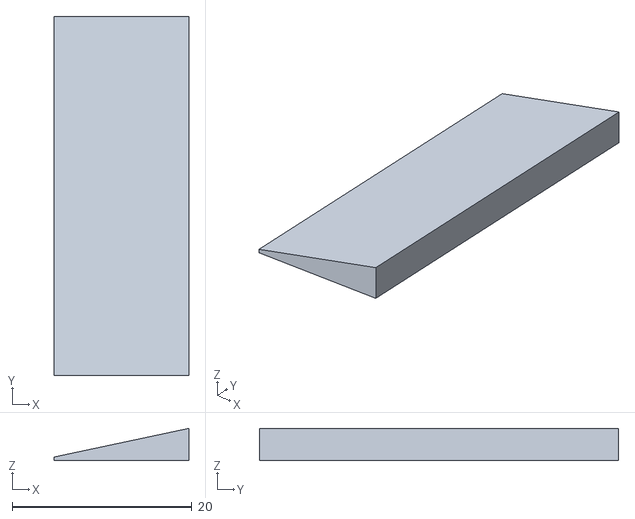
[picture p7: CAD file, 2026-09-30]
docs/design/intake_study/print/A15_RAMP_TPU.stl
15.0 x 40.0 x 3.59

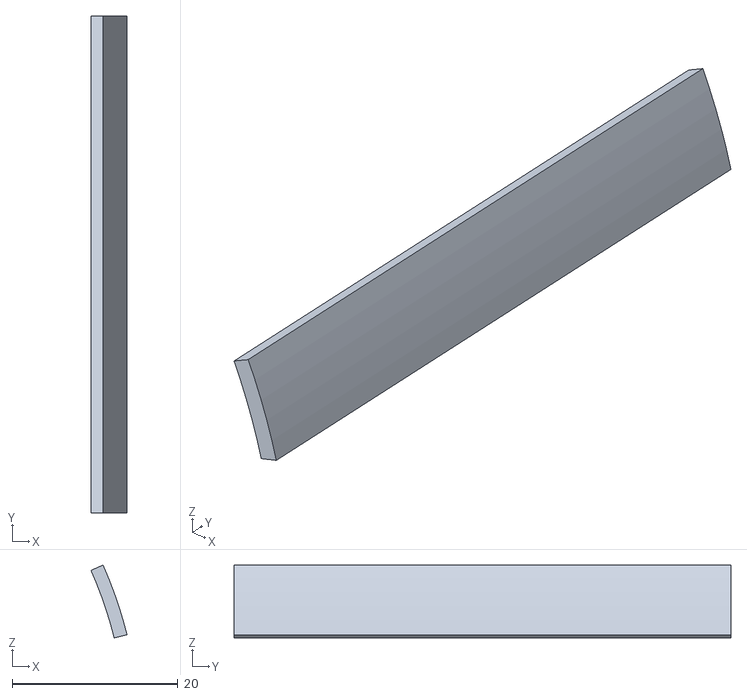
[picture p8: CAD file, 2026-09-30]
docs/design/j1_cover_adopted/J1_COVER_A_ADOPTED.stl
4.36 x 60.0 x 8.81

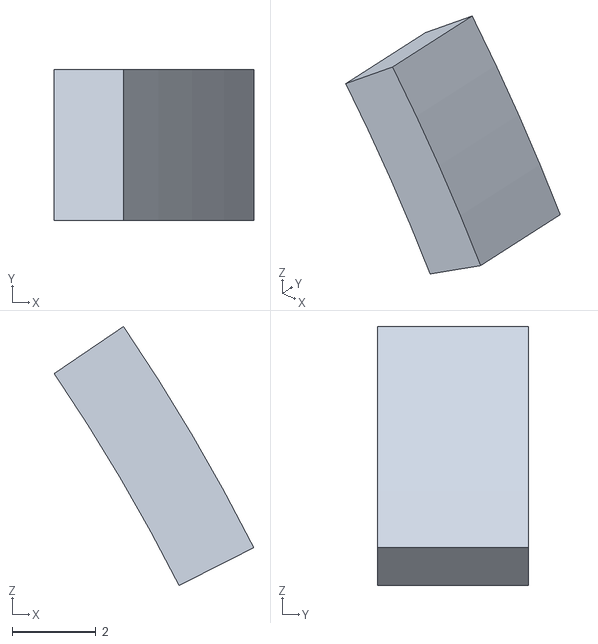
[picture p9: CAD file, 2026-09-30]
docs/design/j1_cover_v2/J1v2_PAD_T6_LO_4.stl
4.76 x 3.60 x 6.18

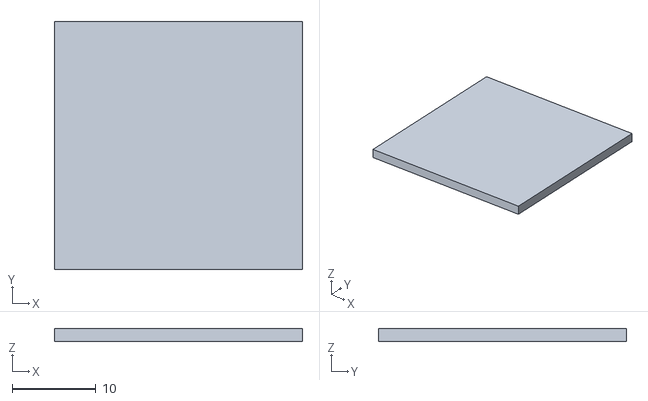
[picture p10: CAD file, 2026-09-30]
docs/design/print_all/P0_B2_hood_pads_plates/B2c_FLOOR_PLATE_T1p5_PLA.stl
29.6 x 29.6 x 1.50

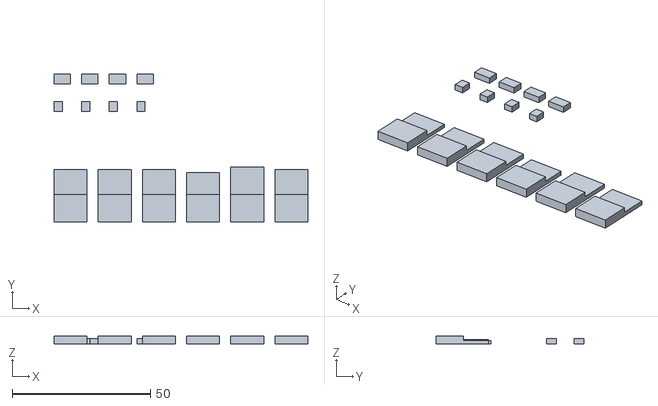
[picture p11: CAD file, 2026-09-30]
docs/design/print_all/P1_HT008_TPU_coupons/HT008_TPU_COUPONS_leaf.stl
92.0 x 53.6 x 3.00

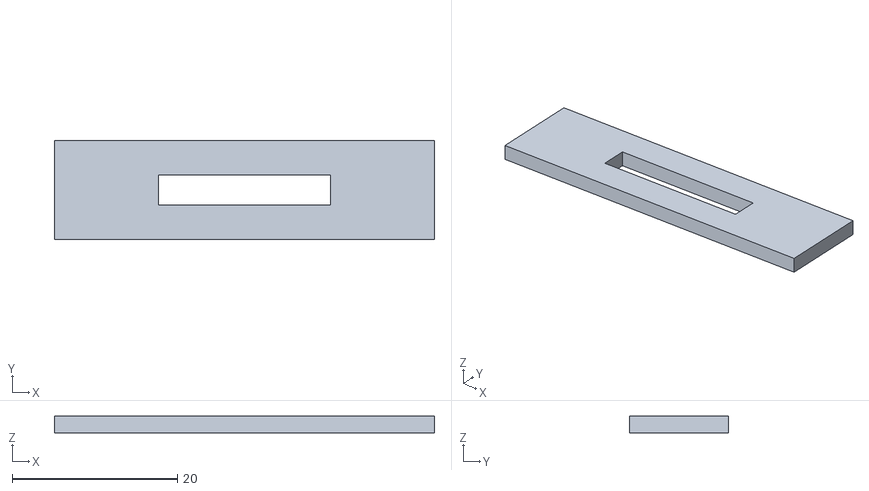
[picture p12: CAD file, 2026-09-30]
docs/design/print_all/P1_HT009_stopper_fit/HT009_WINDOW_STRIP_W20p8.stl
46.0 x 12.0 x 2.00

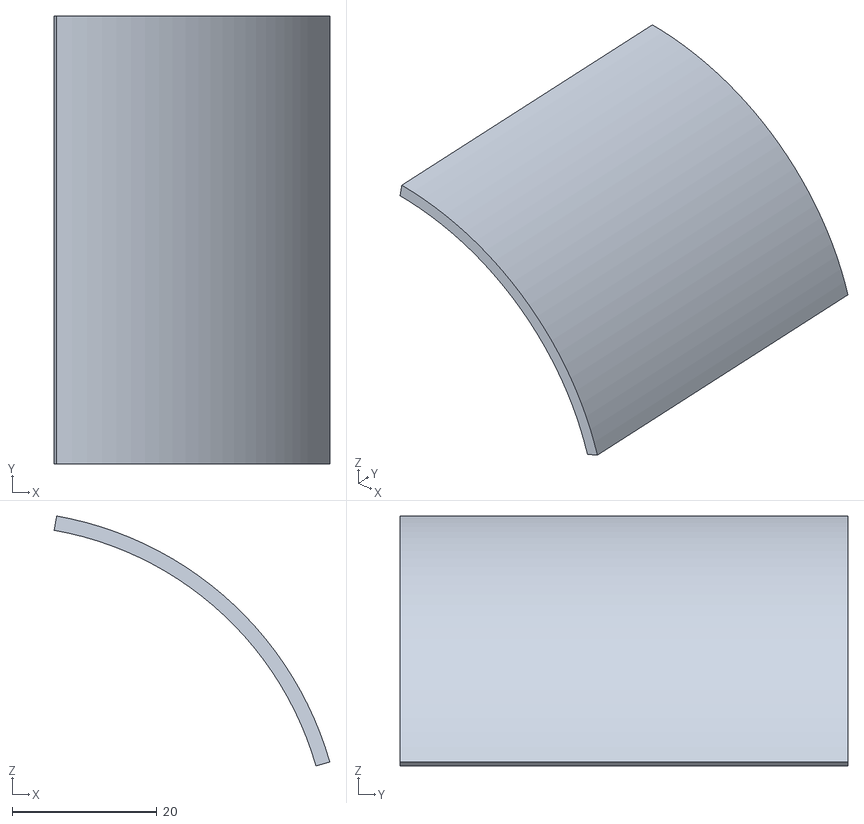
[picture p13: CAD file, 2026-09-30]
docs/design/print_all/P2_HT010_cover_fit/HT010_VISOR_MOCK.stl
38.2 x 62.0 x 34.6

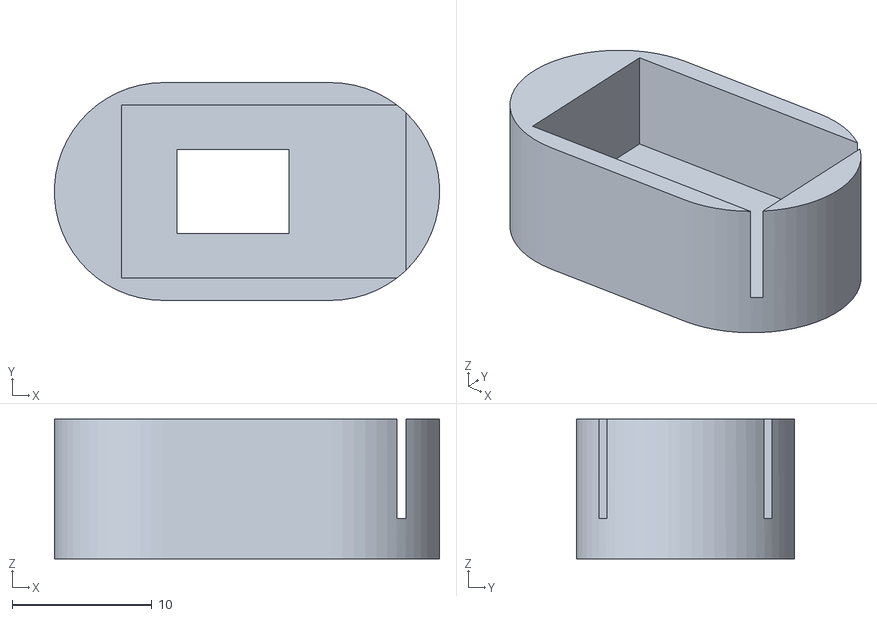
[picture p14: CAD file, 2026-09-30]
docs/design/print_all/P2_HT011_tof_paw_fit/HT011_PAW_MOCK_pocket20p4.stl
27.6 x 15.6 x 10.0

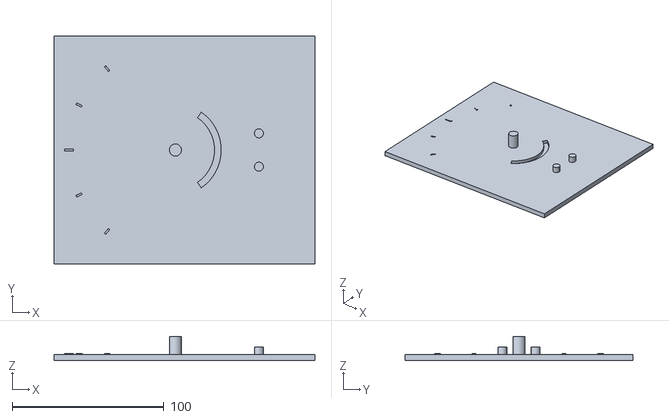
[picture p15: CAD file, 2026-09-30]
docs/design/print_all/P3_knuckle_test_optional/KNUCKLE_R46_PLATE_PLA.stl
172.0 x 150.0 x 16.0

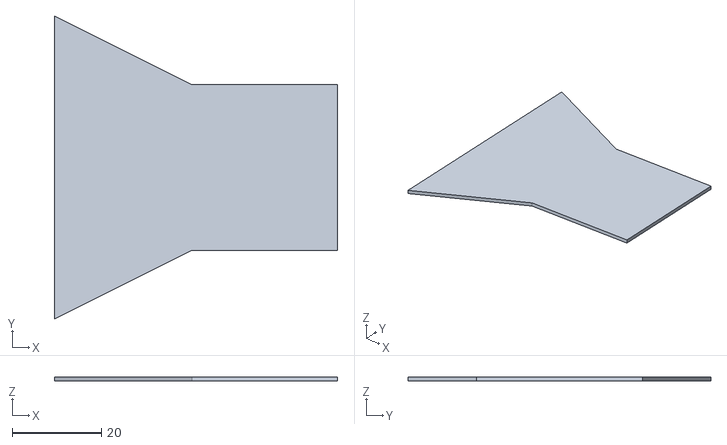
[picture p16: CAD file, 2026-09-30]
docs/design/test_piece_b/B2/print/B2_STEP_SHEET_t1p0_PLA.stl
63.6 x 68.0 x 1.00

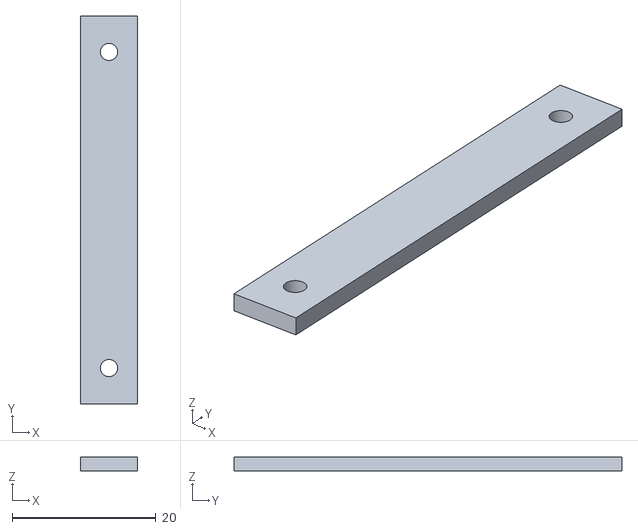
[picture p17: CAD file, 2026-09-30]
docs/design/test_piece_b/print/B1_CLAMP_BAR_PLA.stl
8.00 x 54.0 x 2.00

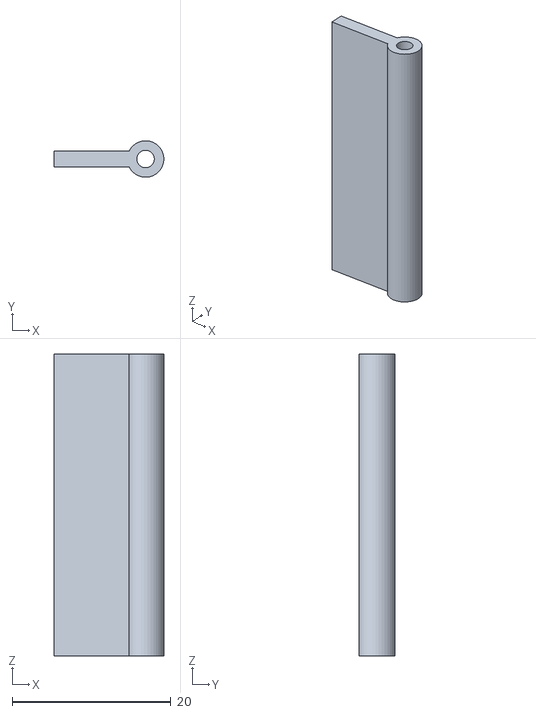
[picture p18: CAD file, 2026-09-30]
docs/design/intake_study/print/A8_ARM_PLA.stl
13.8 x 4.59 x 38.0

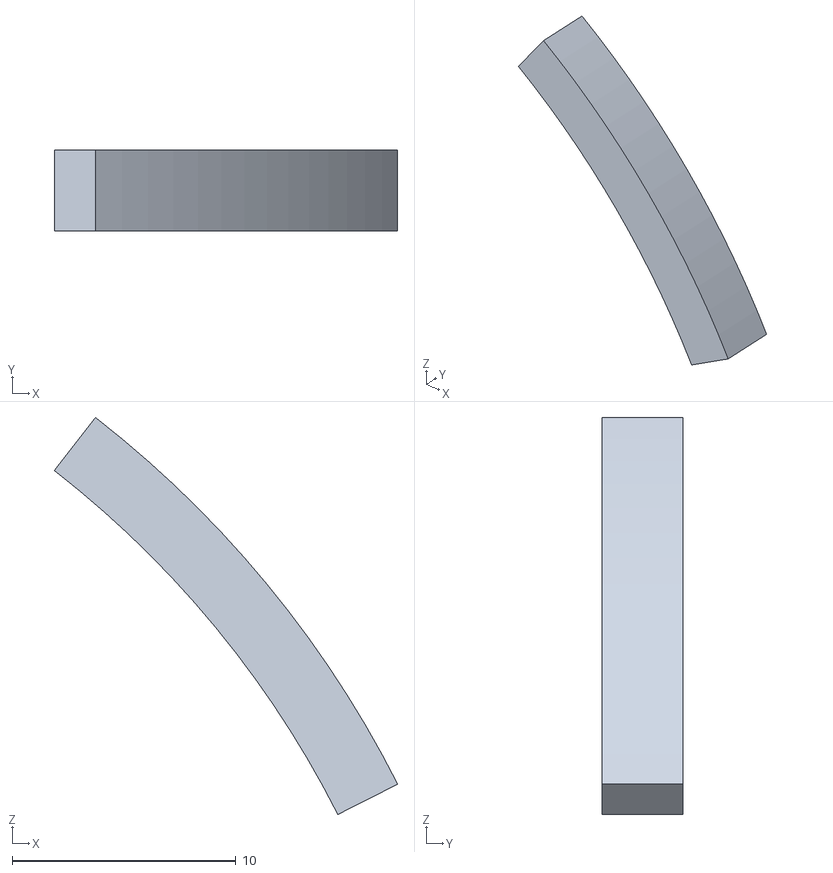
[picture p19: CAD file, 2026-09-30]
docs/design/j1_cover_v2/J1v2_WINDOW_T6_0.stl
15.3 x 3.60 x 17.7

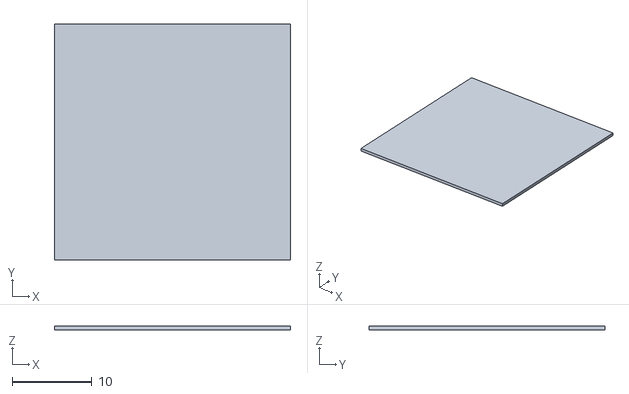
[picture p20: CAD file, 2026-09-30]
docs/design/print_all/P0_B2_hood_pads_plates/B2c_FLOOR_PLATE_T0p5_PLA.stl
29.6 x 29.6 x 0.5

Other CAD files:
docs/design/print_all/P1_HT009_stopper_fit/HT009_WINDOW_STRIP_W14p8.stl
docs/design/print_all/P2_HT010_cover_fit/HT010_COLLAR_SLICE_with_COVER_A.stl
docs/design/print_all/P2_HT011_tof_paw_fit/HT011_PAW_MOCK_pocket18p4.stl
docs/design/print_all/P3_knuckle_test_optional/KNUCKLE_R46_BALL_A_PLA.stl
docs/design/intake_study/print/A15_ARM_PLA.stl
docs/design/intake_study/print/A15_BASE_PLA.stl
docs/design/intake_study/print/A8_BASE_PLA.stl
docs/design/intake_study/print/A8_RAMP_TPU.stl
docs/design/j1_cover/J1_STOP_PIN_1.stl
docs/design/j1_cover/J1_STOP_PIN_3.stl
docs/design/j1_cover/J1_STOP_WINDOW_FULL_2.stl
docs/design/j1_cover/J1_STOP_WINDOW_FULL_4.stl
docs/design/j1_cover/J1_STOP_WINDOW_VARIANT_B_5.stl
docs/design/j1_cover/J1_STOP_WINDOW_VARIANT_B_6.stl
docs/design/j1_cover_v2/J1v2_DOWEL_0.stl
docs/design/j1_cover_v2/J1v2_DOWEL_5.stl
docs/design/j1_cover_v2/J1v2_DOWEL_HOLE_1.stl
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

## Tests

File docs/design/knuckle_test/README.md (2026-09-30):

# KNUCKLE DRUM 試験片（円柱肩 1 関節分）— A1 印刷用（2026-09-30）

> **先頭の注意**: KNUCKLE DRUM を入れても、まっすぐに比べ曲げた姿勢では約 20 倍（18〜24 倍）の体積のすき間が残る（背板の層 約 1020 mm³/姿勢は未解決、J1 ピッチは動作範囲の回答待ち）。**この試験片は胴の層（z 8〜76）の円柱肩だけを確かめるもので、背板の層は含まない。**

**印刷・購入は User が行う（Design は印刷していない）。** 形は Fusion の CAD（Recovery 複製）の実形状から切り出した。数値の由来: **[CAD]** = この CAD の実測、**[A]** = ASSUMED（仮置き）、**[C]** = 計算。

## 2 種類（各 1 セット = 板 + 玉 A + 椀 B）

| 種類 | 代表する関節 | 玉の円柱 | 元のリンク（CAD） | 備考 |
|---|---|---|---|---|
| **R46** | J3・J4・J5 | R 46 [CAD] | 玉 = LINK2（J4）、椀 = LINK3（J4） | J3・J5 も同じ形（J5 の尾は椀側が細い。試験片は J4 の形） |
| **R34** | J2（首） | R 34 [CAD] | 玉 = NECK-V、椀 = LINK1（J2 側） | **椀の形（J2）は測定不足**（縁の角度は R46 と同じと仮定していない。CAD の形をそのまま切っただけ） |

## ファイル（`print/`、STL は **印刷の向きで出力済み**）

| ファイル | 中身 | 向き・支え | 寸法 mm（x×y×z） |
|---|---|---|---|
| `KNUCKLE_R46_BALL_A_PLA.stl` / `R34` | 玉 A（円柱肩＋胴の切れ端）、中心穴 d8.6、案内の突起、後ろの指針 | **上下逆（平らな上面を下）で印刷済み、支え不要** | R46: 112×92×70.2、R34: 99×68×70.2 |
| `KNUCKLE_R46_SOCKET_B_PLA.stl` / `R34` | 椀 B（椀の壁・面取り・胴の切れ端）、位置決めの穴 d6.4 ×2 | 上下逆で印刷済み、支え不要 | R46: 45.7×92×67、R34: 50.9×92×67 |
| `KNUCKLE_R46_PLATE_PLA.stl` / `R34` | 板（軸 d8、位置決め突起 d6 ×2、案内の溝 ±55.7°、目盛り 0/±25/±50） | そのまま平置き | 172×150×16（板 4） |
| `GAUGE_5mm_12mm_PLA.stl` | 探針 d5.0 と d12.0（Go/No-Go。5〜12 mm の帯の確認用） | 立てて印刷 | 64×28×42 |

## 印刷（Bambu A1、PLA）

- ノズル 0.4、層 0.2、壁 3 周以上、**インフィル 15 %**（グリッド／ジャイロイド）、上下 4 層、**支え不要**（玉と椀は平らな面を下にしてある。玉の穴・板の溝は縦向き）。
- 質量の目安（PLA 1.24 g/cm³ [R]。15 % は壁 1 mm 相当 ＋ 内部 15 % の概算 [C]、スライサの値と違う）:

| セット | 部品 | 体積 cm³ | 中実（最大）g | 15 % g（概算） |
|---|---|---|---|---|
| R46 | 玉 A | 493.6 | 612 | 130 |
| | 椀 B | 216.7 | 269 | 65 |
| | 板 | 103.5 | 128 | 77 |
| | **合計** | 813.8 | **1009** | **272** |
| R34 | 玉 A | 300.2 | 372 | 88 |
| | 椀 B | 234.1 | 290 | 68 |
| | 板 | 103.5 | 128 | 77 |
| | **合計** | 637.8 | **790** | **233** |

（「中空」は薄い外殻だけにする場合。この試験片はモデルが中実なので、スライサのインフィル 15 % で軽くする。）

## 組み立て

1. 板の位置決め突起（d6）に椀 B の穴（d6.4）を差して置く（必要なら接着）。
2. 玉 A の中心穴（d8.6）を板の軸（d8）に差す。玉の下の突起（d3.6）が板の溝（幅 4.4）に入る。玉は溝の端（約 ±52°）で止まる（**機構のストッパー 52° に合わせた**）。
3. 玉の後ろの指針を、板の目盛り（0・±25・±50°）に合わせる。

## 確認のしかた

- 玉を 0・±25・±50° にして、探針 d5.0 が **入らない**、d12.0 も入らない、その間（隙間が 5〜12 mm のもの）が無いかを、椀と玉のすき間・面取りの V に当てて見る。
- Python 検査（STL、0.5 mm）では、A と B・板の干渉は **0 mm³**（0・±30・±50・±52°、両種類）。

## 注意・限界

- **[A] の仮置き**: 中心穴・軸・突起・溝・指針・目盛り・板の寸法。試験用の治具で、ロボットの部品ではない。
- R34 の椀 B の STL に **開いた辺 18 か所**（0.001 mm 丸めでの検査）。スライサの「修復」で直る見込みだが、確認していない。
- 試験片は胴の層（z 8〜76）。背板の層・ケーブル・内部・公差は入っていない。人の手で確かめるのは **外形とすき間の感触** まで。
- Fusion: `KNUCKLE TEST R46 / R34 A1 print …`（組立の位置）と `… PRINT ORIENTATION …`（印刷の向き、非表示）。名前に [CAD] / [A] / [C] を書いた。

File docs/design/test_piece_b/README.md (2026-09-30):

# 試験片 B — 漏斗つき開放底フード（2026-09-30、A1 印刷用）

**印刷・購入は User が行う（Design は印刷していない）。** 数値の由来: **[B]** = User の依頼、**[A]** = ASSUMED（仮置き）、**[C]** = この CAD から計算、**[R]** = 一般に公表されている値（この部品で確かめていない）。**由来は Fusion のコンポーネント名・ボディ名にも書いた。**

> **解釈が要る所（Design の仮定）**: (1) 依頼の「試験片 B」の元のブリーフは、この会話には無い（A = 巻き込みくちばしの続きと読んだ）。(2) **前縁の「段差 0 / 0.3 / 1 mm」を、リップ板の下面が床から浮く高さ（0 / 0.3 / 1.0 mm）と解釈**した。違う意味なら形を直す。(3) スカートが付くとフード全体が H だけ床から上がるので、リップの高さは H + step になる（別々に試す）。

Fusion: `Serpens_FW02_HEAD_INTAKE_STUDY01_NOT_FOR_PRINT` の中の `TEST PIECE B1 funnel hood - …`（組立の位置）と `TEST PIECE B1 PRINT ORIENTATION …`（印刷の向き、非表示）。元の体（FW02）は変えていない。

## 部品（`print/`、STL は印刷の向きで出力済み）

| ファイル | 材料 | 数 | 中身と寸法 |
|---|---|---|---|
| `B1_HOOD_PLA.stl` | PLA | 1 | 漏斗つきフード。**口 60 → 奥 30 mm（深さ 30）[B]、その奥に空間 30×30×15 [B]**（高さ 15 は全体）。**開放底**。壁 1.6 mm [A]（[B] 最小 1.2 以上）、屋根 1.6、足の帯 3.6×4（スカートの溝用）[A]。傾き 0.5（半幅 30 → 15 を 30 で）[C]。**屋根を下にして印刷済み（支え不要）**。外形 83.6×80×19.6（耳・クランプ座・ロッド受け込み） |
| `B1_LIP_PLA.stl` | PLA | 1 | 前縁のリップ板。厚さ 1.2 [A]、前縁は上面が 12° のランプで先端厚 0.6 [A: くちばしの試験片 A の値]。耳（2 か所）にペグ d2.3 ×3.0 [A]。**外形 21×80** |
| `B1_SPACER_STEP0_t1p0_PLA.stl` | PLA | 2 個入り | 厚さ 1.0 のワッシャー（外径 7、穴 2.6）[A]。**段差 0 mm 用** |
| `B1_SPACER_STEP0p3_t0p7_PLA.stl` | PLA | 2 個入り | 厚さ 0.7。**段差 0.3 mm 用** |
| （スペーサーなし） | | | **段差 1.0 mm**（リップの上面が耳に直接当たる） |
| `B1_CLAMP_BAR_PLA.stl` | PLA | 1 | 垂れ布のクランプ棒 54×8×2 [A]、M2 用の穴 d2.4 ×2 [A] |
| `B1_SKIRT_H3_TPU.stl` / `B1_SKIRT_H6_TPU.stl` | TPU | 各 1 セット（5 本入り） | スカート（差し替え式）。**見える高さ 3 / 6 mm [B]**、厚さ 1.15、舌 2.5 が足の帯の溝（幅 1.2 [A]）に入る。5 本 = 漏斗の左右（各 34 mm）、空間の左右（各 31.4）、後ろ（33.6） |

## 機能の組み立て

- **段差の切り替え**: リップのペグ 2 本を、（スペーサー 2 個を通して）フードの耳の穴に差す。段差 0 = 厚さ 1.0、0.3 = 厚さ 0.7、1.0 = スペーサーなし。リップの下面の高さ = 1.0 − スペーサーの厚さ（床から）。ペグは摩擦（必要なら少量の接着）。
- **垂れ布の取り付け部**: 屋根の前縁の座（8×54×3）に、TPU の薄板 **0.4〜0.6 mm [B]** を載せ、クランプ棒を M2 ねじ ×2（下穴 d1.6、深さ 3.2 [A]）で留める。布は前縁から前・下へ垂らす（受け身の垂れ布）。
- **スカート**: 足の帯の下面の溝に、TPU の舌を差し込む（差し替え式）。
- **棒 φ8 の差し込み穴**: 後ろのブロック 22×22 に **d8.4**（φ8 + 0.4、くちばしの試験片 A の rod_d + 0.4 と同じ [A]）、深さ 20。手で棒を押して進める。**止めねじは無い**（[A] 必要なら M3 を足す）。

## 試す物（フードの空間 30×30×15 に入るか。口 60 から入れる）

| 物 | 寸法 | 由来 | 入るか（形の上） |
|---|---|---|---|
| 1 円玉 | φ20 × 1.5 | [R]（公表値） | 入る（高さ 15、幅 30） |
| CR2032 | φ20 × 3.2 | [R] | 入る |
| ビーズ | User の手持ち | — | 直径が 15 以下なら入る |
| 立方体 | User の手持ち | — | 一辺 15 以下（空間は 30×30×15）。斜めに入れる場合は対角 |

**空間の後ろの壁が閉じているので、物は止まる**（押し出す向きの試験）。前縁の段差・布・スカートの有無で、入る／戻ってくる／下をくぐる、を比べる。判定の基準は Design は持っていない（User の観察）。

## 印刷

- PLA: 0.4 ノズル、層 0.2、**壁 4 周（1.6 mm）**、インフィル 15 %（フードは壁だけでほぼ中実）。フードは屋根を下にして置く（STL のまま）。ロッド穴は水平（小さいので橋渡し可。だめならティアドロップに直す）。
- TPU（95A 程度 [A]）: **A1 では外付けスプールで、AMS を通さない**。0.4、層 0.2、低速（20〜30 mm/s）、リトラクション最小。スカートは寝かせて印刷済み。
- 質量（概算 [C]）: フード 21 g（中実）、リップ 1.7 g、クランプ棒 1.1 g、スペーサー 各 0.1 g 以下、スカート H3 1.2 g / H6 1.9 g（TPU 1.2 g/cm³ [R]）。

## 限界

- 形の確認は Fusion の STL の断面（`b1_check.png`）まで。**実物の嵌合・摩擦・TPU の柔らかさ・ペグの保持は未確認**。
- 壁 1.6 は [B] の最小 1.2 以上だが、ロッド穴の上下の壁（4.1）・足の帯の溝の側壁（1.2）が最小ぎりぎり。
- スカートを付けるとフードが H 上がり、リップの床からの高さが変わる（上の (3)）。
- 前縁の段差の解釈が違う場合は、リップ板とスペーサーだけ作り直せばよい（フード本体は共通）。

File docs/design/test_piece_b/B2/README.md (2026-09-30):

# 試験片 B2 — 漏斗つき開放底フード（段差 t とすき間 c を独立に変える）

> **【常に先頭に置く注意】KNUCKLE DRUM を入れても、まっすぐ（124 mm³）に比べ、曲げた姿勢では 2250〜2939 mm³ のすき間の体積が残る（約 20 倍、18〜24 倍）。背板の層（z ≥ 77）約 1020 mm³/姿勢は未解決、J1 ピッチは範囲の確認待ち。** 数値は CAD_CONCEPT / KINEMATIC_SIM。**安全・合格の語は使わない**。5.7 N・0.25 N·m は暫定（SAFETY_UNVERIFIED）。

**B1（`../README.md`、`../print/`）は上書きしていない。B1 のリップ（下面が床から浮く高さ 0 / 0.3 / 1.0）は、下の c に近く、Engineering の t を表せなかったので、B2 を別に作った。**

数値の由来: **[E]** = Engineering のシミュ（`simulation/scoop/forms`、`config/scoop.yaml`）のパラメータ、**[B]** = User の依頼、**[A]** = ASSUMED、**[C]** = 計算。由来は Fusion のコンポーネント名・ボディ名にも書いた（`TEST PIECE B2 …`、FW02 intake 複製の中）。

## 0. 「段差 0」の意味（先に読む）

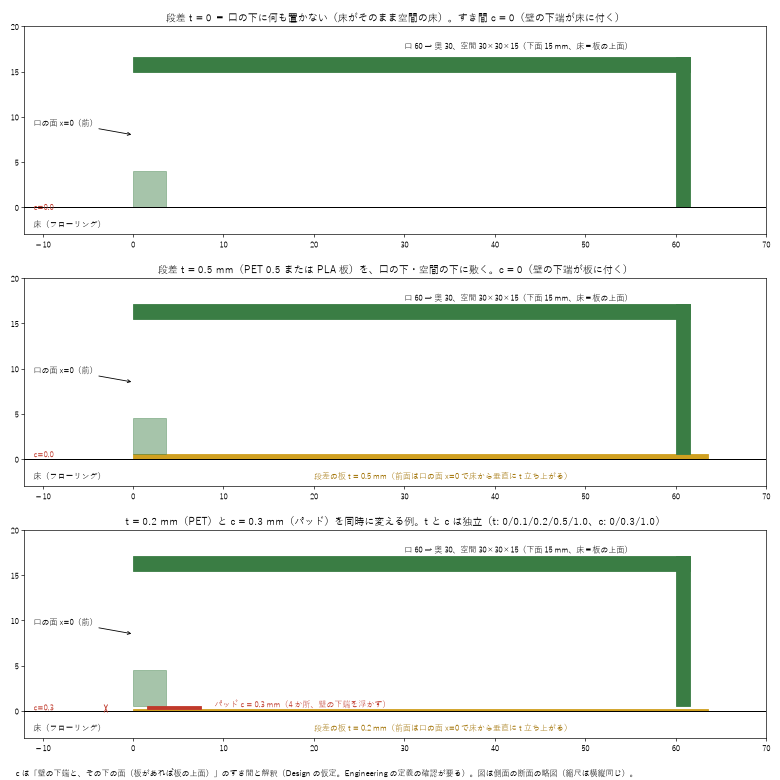
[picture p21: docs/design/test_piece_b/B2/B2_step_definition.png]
t と c の定義


- **段差 t = 口の下（と空間の下）に敷く「床の板」の厚み。板の前面が、口の面（x = 0）で床から t だけ垂直に立ち上がる。** 振る値 [E]: **0 / 0.1 / 0.2 / 0.5 / 1.0 mm**。
- **t = 0 は「口の下に何も置かない」こと。床がそのまま空間の床になる。**（板が薄いほどではなく、無いのが 0。Engineering のシミュでは t = 0.1 mm で全対象物の保持が 0 % に戻る。）
- **すき間 c = 壁の下端が、その下の面から浮く高さ。** 振る値 [E]: **0 / 0.3 / 1.0 mm**（シミュの既定 0.1）。
- **t と c は独立。** t は薄板（PET 0.1 / 0.2、PLA 0.5 / 1.0、マスキングテープ 1 枚 ≈ 0.1）で、c は差し替えパッドで切り替える。
- **Design の仮定（要確認）**: c は「壁の下端と、板があれば板の上面、無ければ床」のすき間とした。シミュが c を床から測るなら、t > c のとき壁の下端が板の中に入る組み合わせが出る。**Engineering に確認する**（ENTRY-D-0006）。

## 1. 部品（`print/`）

| ファイル | 材料 | 数 | 中身 |
|---|---|---|---|
| `B2_HOOD_PLA.stl` | PLA | 1 | フード本体。口 60 → 奥 30（深さ 30）[B]、空間 30×30×15 [B]、壁 1.6 [A]（シミュは 1.0、印刷の最小 1.2 以上にした）、足の帯 3.6×4 [A]、**壁の下端の面取り 0.3 [A]（象の足の対策）**、スカートの溝 1.2×2.5 [A]、垂れ布の座 8×54×3 と M2 の下穴 d1.6 [A]、ロッド穴 d8.4 深さ 20 [A]。**壁の下端を下（第 1 層）にした向きで出力済み** |
| `B2_STEP_SHEET_t0p5_PLA.stl` / `t1p0` | PLA | 各 1 | 段差の板 t = 0.5 / 1.0。外形は足の帯の形（63.6 × 68）。**前縁が口の面 x = 0** |
| `B2_STEP_SHEET_template_1to1.svg` | — | — | **PET 0.1 / 0.2 mm、マスキングテープ（0.1 mm）の切り出し用の外形（等倍）**。前縁（左）が口の面 |
| `B2_PADS_c0p3_x4_PLA.stl` / `c1p0` | PLA | 各 4 個 | すき間 c = 0.3 / 1.0 のパッド（3.4×8）。**c = 0 はパッドなし** |
| （B1 のスカート TPU、`../print/B1_SKIRT_H3_TPU.stl` ほか） | TPU 95A | 任意 | 溝は B2 のフードと同じ。**付けるとフードが H だけ上がる（c に H が足される）ので、t・c の試験とは別に使う** |
| （B1 のクランプ棒、`../print/B1_CLAMP_BAR_PLA.stl`） | PLA | 1 | 垂れ布（TPU 0.4〜0.6）をフードの座に M2 ×2 で留める |

## 2. 組み立て（t・c の切り替え）

1. **段差の板**（t）を作る: t = 0.1 / 0.2 は PET シートを外形のテンプレートで切る（マスキングテープは 1 枚 ≈ 0.1 で、重ねて 0.2）。0.5 / 1.0 は PLA の板。t = 0 は何も敷かない。
2. 板を、試験の床の上に**両面テープで貼る**（フードは板の上に載せて動かす）。前縁（口の面に合わせる線）を、床のマスク（マスキングテープの線）で決める。
3. **パッド**（c）を、フードの足の帯の下面 4 か所（前 2、奥 2。位置は STL の配置のとおり）に両面テープで貼る。c = 0 はパッドなし（壁の下端が板に付く）。
4. フードを載せる。ロッド穴に φ8 の棒を差して手で押す。

## 3. 印刷（Bambu A1）

- **PLA、0.4 ノズル、層 0.2、壁 4 周（1.6 mm）、インフィル 15 %。向きは STL のまま（壁の下端が第 1 層側）。支え: 屋根（幅 60 → 30 の橋渡し）は橋渡しで可（だめなら、屋根の下だけの支え）**。
- **象の足（第 1 層のはみ出し 0.1〜0.2 mm）の対策**:
  1. スライサの「象の足補正（Elephant foot compensation）」を **0.15〜0.2 mm**。
  2. モデルの壁の下端に **0.3 mm の面取り**を入れてある（外側・内側）。
  3. **印刷後、底面をやすり掛け**: ガラス板の上に耐水ペーパー #400 → #800 を貼り、フードを軽く押しながら 8 の字に動かし、**足の帯の下面が全周で均一につやが出るまで**（片当たりが無くなるまで）。
  4. 確認: 平らな板の上に載せ、下から光を当てて**光が漏れない**こと。0.1 mm のシックネスゲージ（または PET 0.1 の切れ端）が壁の下に**入らない**こと（c = 0 の場合）。
  5. 板・パッドも同じ向きで、同様に底面を軽く整える（パッドは厚みが c なので、やすり掛けは表面のバリ取りだけ）。
- **TPU（スカート）**: A1 では外付けスプール、AMS を通さない、低速。

## 4. User が見る観察項目

物: 1 円玉（φ20×1.5 [R]）、CR2032（φ20×3.2 [R]）、ビーズ（φ8）、立方体（10 mm）。床: 硬い床（フローリング）とマット。**絨毯は未対応**（毛にすき間が埋まる。Engineering の前提のまま）。

各条件（t × c の 15 通り）× 物 で、頭（フード）を手で押して次のどれかを記録する（`B2_test_log_template.csv`）:

| 記録 | 意味 |
|---|---|
| **入る** | 物が空間の中（奥の壁の前）に入った |
| **戻る** | いったん入ったが、押す向きを止める・戻すと口から出た |
| **下をくぐる** | 物が壁の下端の下をくぐった（c が大きいとき） |
| 押されて逃げた | 物が口の前で押されて、入らなかった（t が大きいとき） |
| 挟まった | 物や指が壁と床・板のあいだで動かなくなった |

**Engineering のシミュとの比較**: t = 0 で入り、t = 0.1 でも入らなくなるか（シミュは 0 %）。c が 0.3 / 1.0 のとき、1 円玉（厚み 1.5）と CR2032（3.2）が下をくぐるか（c 1.0 でも 1.5 のほうが厚い）。

## 5. 限界

- **形の確認は STL の断面まで。実物の嵌合・摩擦・パッドの貼り付き・PET の平らさは未確認。**
- シミュの壁は 1.0 mm、B2 は 1.6 mm（壁の外側が広い → 漏斗の前縁が少し鈍い）。空間の内寸は 30 のまま。
- ゲート（口の面に立つ板）は含めていない（受け身の垂れ布の座のみ）。
- 絨毯・毛は未対応。安全（指・しっぽの挟み込み）は未確認。**安全・合格とは言えない。**

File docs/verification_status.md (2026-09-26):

# 検証レベル — 何が確かめられていて、何が確かめられていないか

作成 2026-09-15、2026-09-21 に 5 段へ。**このリポジトリで「確認済み」と書くときは、必ずこのどれかを指す**
（`serpens/verification.py`）。実機が 1 台も無い状態で開発しているので、**模擬の結果を実測として扱わない**ことが最優先。

| レベル | 意味 | 根拠になるもの |
|---|---|---|
| `SOFTWARE_VERIFIED` | **ソフトの論理として正しい**ことを自動試験で確かめた（物理は含まない） | `pytest`。式の一致・状態遷移・拒否条件・値の整合 |
| `KINEMATIC_SIM` | 簡易シミュレータで**そう動いた**（車輪の横滑りゼロ拘束・指令角そのまま）。旧表記 `SIMULATED` | `serpens/sim`、`tools/motion_quality.py`、`tools/body_compare.py` |
| `PHYSICS_SIM` | MuJoCo（接触・摩擦・サーボの一次遅れ）でそう動いた。摩擦もゲインも未同定 | `simulation/mujoco` |
| `HARDWARE_VERIFIED` | **実機で測った**。日付・条件・測定器つき | 実測記録 |
| `HUMAN_EVALUATED` | **人が見て評価した**。source は `VIDEO_HUMAN_EVALUATION`（動画）/ `PHYSICAL_HUMAN_EVALUATION`（実物） | `docs/human_pilot.md` の回答 |

設計値・推定値で実機が要るものは従来どおり `HARDWARE_UNVERIFIED` と書く。
現在 `HARDWARE_VERIFIED` は **0 件**、`HUMAN_EVALUATED` は **0 件**。
**Snake-likeness / Animacy / Approachability / Affection / Fear / Smoothness は Simulation だけでは合格判定しない。**
`tools/motion_quality.py` の指標は REGRESSION_METRIC / SIMULATION_DIAGNOSTIC であり、人の評価の代替ではない。

## 1. 駆動リンクと安全

| 項目 | レベル | 根拠 |
|---|---|---|
| フレーム（CRC・分割・混入・seq） | `SOFTWARE_VERIFIED` | `tests/test_phase2_frame.py`（8） |
| 7状態の状態機械 | `SOFTWARE_VERIFIED` | `tests/test_phase2_device.py` / `test_phase2_safety.py` |
| PC 強制終了・USB 抜去で機体が止まる | `SIMULATED` | 偽経路で再現。**実機の停止時間は未測定** |
| 通信断 → 保持まで 210〜300ms | `SIMULATED` | `tools/link_check.py`。実機ではシリアル往復ぶん増える |
| 緊急停止 → 出力停止 10ms | `SIMULATED` | 同上。**実機では 9軸同期書き込みの時間が乗る** |
| 上限外の角度・速度・歩容値の拒否 | `SOFTWARE_VERIFIED` | `tests/test_phase2_device.py`（11 種） |
| NaN / Inf / 桁あふれを送らない | `SOFTWARE_VERIFIED` | `tests/test_phase2_faults.py` |
| packet loss / delay / 順序入れ替え / 重複 / CRC 破損 | `SIMULATED` | `tests/test_phase2_faults.py`（17） |
| サーボ応答なし → FAULT_HOLD | `SIMULATED` | 模擬サーボを offline にして確認 |
| 過熱・fault ビットでラッチ | `SIMULATED` | 模擬サーボの値。**実機の温度挙動は未測定** |
| ファームと Python の値の一致 | `SOFTWARE_VERIFIED` | `tests/test_firmware_sync.py`（11） |
| ファームのビルド | `SOFTWARE_VERIFIED` | `tools/build_firmware.py`（arduino-cli + esp32 core 2.0.17, XIAO_ESP32S3）。フラッシュ 7% / RAM 5%。**書き込みはしていない** |

## 2. 機構・サーボ

| 項目 | レベル | 根拠 |
|---|---|---|
| 可動域 geometry ±90° | `HARDWARE_UNVERIFIED` | 設計値 |
| 干渉の始まり 64.8°（干渉なし）〜 64.9°（干渉） | `HARDWARE_UNVERIFIED` | CAD R03 の検討結果（verified_in_cad）。**clamp には使わない。** ケーブル込み・実物では未確認 |
| mechanical_design_limit ±55°（PROVISIONAL） | `HARDWARE_UNVERIFIED` | CAD R03 の提案値 |
| software_operational_limit ±50°（CONDITIONAL） | `HARDWARE_UNVERIFIED` | 実機試験の**候補値**であって実機運転の許可ではない。`config/robot.yaml` の `joint_limit_policy` |
| 最小曲げ半径 82.3mm / 輪の内径 114mm | `SOFTWARE_VERIFIED` | 幾何計算（`tests/test_safety_limits.py`）。**外皮を着せた実物では変わりうる** |
| とぐろが自己干渉しない（クリアランス 89.6mm） | `SOFTWARE_VERIFIED` | 中心線の距離計算。外皮の厚みは未考慮 |
| ソフトのトルク上限 0.450N·m（ストール参照比 0.287） | `HARDWARE_UNVERIFIED` | C044（7.4V/1:191）の**参照値**（rated 5.2 / stall 16 kgf·cm）から。`measured_safe_torque_nm` は null |
| ELECTRICAL_SAFETY_GATE（8項目） | **全項目 INCOMPLETE** | `docs/safety_limits.md` §5。閉じている間は実機の自律走行を拒否（`SOFTWARE_VERIFIED`: `tests/test_electrical_gate.py`） |
| 接触 → 脱力 20ms | **未達・要求未確定** | `docs/contact_release_requirements.md` |
| 挟み込み力 12.4N | `HARDWARE_UNVERIFIED` | 計算値。ISO/TS 15066 との比較も未（規格本文を参照できていない） |
| サーボの応答（一次遅れ・速度上限・温度上昇） | `SIMULATED` | `mock_servo` の係数はすべて仮値 |
| STS3215 のレジスタ仕様 | `HARDWARE_UNVERIFIED` | 一次資料（Waveshare/Feetech）で確認済みだが実機で試していない。`docs/sts3215_registers.md` |
| 最高入力電圧の初期値 8.0V（12V の罠） | `HARDWARE_UNVERIFIED` | メモリテーブル記載。**実機で最優先に確認する** |
| 負荷の符号ビット（bit10 仮説） | `HARDWARE_UNVERIFIED` | 公式資料に記載なし。仮説のまま |

## 3. 移動・歩容

| 項目 | レベル | 根拠 |
|---|---|---|
| 歩容の式と機体の出力が一致（差 < 1e-9°） | `SOFTWARE_VERIFIED` | `tests/test_phase2_device.py` |
| 1周期あたり 390mm 前進（6軸・振幅30°） | `SIMULATED` | `tangential_drag_ratio = 0.02` は**推定値**。実測で変わる |
| 旋回半径 388mm（γ0=20°） | `SIMULATED` | 同上 |
| 胴体ヨーの本数と移動性能の関係 | `SIMULATED` | `docs/product_status.md` §3。相対比較にのみ使う |
| マット端に寄らない（0.00%） | `SIMULATED` | 仮想フェンス。実機の滑りは未検証 |
| 摩擦（Wheel Belly / Snake Belly） | `HARDWARE_UNVERIFIED` | **Snake Belly の摩擦係数は未実測。** 仮値を現実として扱わない |
| 騒音 | **未測定** | 構想設計書が「最大のリスク」とする項目。実機が来たら最初に測る |

## 4. 知覚・行動

| 項目 | レベル | 根拠 |
|---|---|---|
| ArUco 検出（1080p で 50mm マーカ） | `SOFTWARE_VERIFIED` | 実写画像で検出率を測定済み（印刷物は実物） |
| 床ホモグラフィ・視差補正 | `SIMULATED` | 仮想カメラでの検証。実カメラでの誤差は未測定 |
| YOLO 人物検出（オフライン） | `SOFTWARE_VERIFIED` | `tests/test_offline.py`。ネット遮断で最後まで動く |
| 行動の状態遷移・効用調停 | `SOFTWARE_VERIFIED` | `tests/test_behavior_*.py` |
| 「生き物らしさ」 | **未評価** | 人が見ての評価。実機でしか判断できない |

## 4.5 仮想実機（Phase 2/3）

| 項目 | レベル | 根拠 |
|---|---|---|
| `SimulatedSnake`（PC → 仮想ESP32 → 仮想サーボ → シミュレータ） | `SIMULATED` | `tests/test_phase3_link_robot.py`（12） |
| `RealSnake`（PC → 実 ESP32 → STS3215） | **`HARDWARE_UNVERIFIED`** | 一度も実ポートで通信していない |
| 7状態の遷移（FAULT_HOLD からの復帰は DISARMED まで） | `SOFTWARE_VERIFIED` | `tests/test_phase2_safety.py` |
| テレメトリ v2（velocity / age / ttl / overrun / source） | `SOFTWARE_VERIFIED` | `tests/test_phase2_frame.py` |
| 仮想サーボの応答（一次遅れ・速度上限・温度・電圧降下） | `SIMULATED` | `mock_servo` の係数は仮値 |
| GUI の関節ペイン（指令角 / 実測角 / 機体状態） | `SOFTWARE_VERIFIED` | オフスクリーン描画テスト + 目視（output/gui_joints.png） |
| Belly（wheel / snake）と摩擦プロファイル | `SIMULATED` | `tests/test_belly_and_gait_config.py`。**係数は未実測** |
| 歩容の掃引（速さ・蛇らしさ・滑らかさ・負荷） | `SIMULATED` | `tools/gait_sweep.py` |

## 4.6 3D 物理・閉ループ（Stage F〜N）

| 項目 | レベル | 根拠 |
|---|---|---|
| MuJoCo モデル（9軸・質量・可動域・トルク上限が config と一致） | `SOFTWARE_VERIFIED` | `tests/test_mujoco_model.py`（10） |
| MuJoCo での推進・旋回・転倒しないこと | `SIMULATED` | `tests/test_mujoco_belly.py`（6）。**摩擦も質量も未実測** |
| 等方摩擦では進まない / 異方性で進む | `SIMULATED` | 簡易シミュレータと **別モデルで独立に一致** |
| サーボゲイン（未同定）で前進量が ±45% 変わる | `SIMULATED` | 実機が来たら最初に同定する（下記） |
| World State の出どころ分離（真値 ≠ Vision） | `SOFTWARE_VERIFIED` | `tests/test_closed_loop.py` |
| 閉ループ（行動 → 機体 → 世界）と故障注入で安全が勝つこと | `SIMULATED` | `tests/test_closed_loop.py`（13） |
| run の記録から同じ run を作れること | `SOFTWARE_VERIFIED` | 同上（seed / config hash / model digest） |

## 4.7 Vision Bridge（Phase 4、`docs/phase4_vision_bridge.md`）

| 項目 | レベル | 根拠 |
|---|---|---|
| 仮想カメラ画像 → ArUco → 自己位置 → 行動 → 仮想機体 の閉ループ | `SIMULATED` | `tests/test_vision_bridge.py`（9）。位置誤差 p95 約 31mm（**模擬画像**） |
| 模擬 Vision を実機の開始条件として通さない（`aruco_sim`） | `SOFTWARE_VERIFIED` | 同上 |
| 自己位置が 0.5s 古くなったら保持し、自動で再開しない | `SIMULATED` | 暗転 3 秒で確認。停止までの惰性 約 31mm |
| 同じ ID の重複を使わない / 位置の飛びを捨てる | `SOFTWARE_VERIFIED` | 同上 |
| 近い偽マーカの区別 | **未対策** | 方式の限界。運用規則で避ける |
| 実カメラでの誤差・遅れ | **未測定** | `vision_sim.latency_s` / `frame_hz` は想定値 |
| 実画像（録画ファイル）→ デコード → ArUco → 自己位置 → セッション | `SIMULATED` | `tests/test_camera_observer.py`（5）。仮想カメラの画像を MJPG 動画にして読み直した。p95 誤差 < 25mm。**実カメラの画像は未** |
| 録画（`aruco_file`）は実機の開始条件を満たさない / 生きたカメラ（`aruco`）だけが満たす | `SOFTWARE_VERIFIED` | 同上 |
| 見失った後（と最初）の自己位置は人が K で確認するまで走行に使わない | `SOFTWARE_VERIFIED` | `tests/test_vision_bridge.py` / `test_camera_observer.py` |
| 50Hz 制御周期が知覚スレッド（ArUco + YOLO 59ms/枚）と同時でも遅れない | `SOFTWARE_VERIFIED`（このPC） | `tools/loop_timing.py`: 平均 19.96ms / 最悪 20.9ms / 遅れ 0/502（2026-09-18） |
| 電子系（遮断器・E-STOP・電流検出）の設計 | **設計案のみ** | `docs/electronics.md`。C044 の電流値は **UNKNOWN**（12V 品の 2.7A は流用しない） |

## 4.8 動きの質（蛇らしさ・愛着。`docs/motion_quality.md`）

| 項目 | レベル | 根拠 |
|---|---|---|
| 静止率 0.44 / 一次反応 0.22s / GAR 0.51 / 可視波数 1.3 / LDJ −25.7 | `SIMULATED` | `tools/motion_quality.py`、`tests/test_motion_quality.py`（7）。KINEMATIC_SIM |
| Bug-1/2/3（Stress 飽和・Energy・ノイズ）の回帰 | `SOFTWARE_VERIFIED` | `tests/test_behavior_units.py` / `test_behavior_sim.py` |
| 人を追跡中に J7 > look_max_deg を指令しない（威嚇の封印） | `SOFTWARE_VERIFIED` | `tests/test_behavior_sim.py` |
| 頭の先端加速度 ≤ 1G・立ち上がり ≥ 200ms | `SOFTWARE_VERIFIED` | `tests/test_animator.py`（指令角。サーボ応答は含まない） |
| 8 軸案で体に 2 波（Ω=90°）、前進は 1 波の約 4 割 | `SIMULATED` | `config/robot_yaw8.yaml`。実機は存在しない |
| カメラ経路込みの一次反応（約 0.52s） | **未測定・窓の外** | detect 5Hz + 遅れ 0.1s は想定値 |
| 「生き物らしさ」「愛着」 | **未評価** | 人が見ての評価。実機でしか判断できない |

## 4.9 Human Perception Pilot の準備（2026-09-21）

| 項目 | レベル | 根拠 |
|---|---|---|
| 6 / 8 / 10 Yaw の overlay（同等リンク長 / 同等身体長）と波数掃引・速度合わせ | `KINEMATIC_SIM` | `tools/body_compare.py` → `output/body_compare.md` |
| 匿名クリップ生成・提示順のランダム化・回答テンプレート・集計 | `SOFTWARE_VERIFIED` | `tests/test_pilot_tools.py`（8） |
| EXHIBITION profile の体験弧（NOTICE→…→REST が 60 秒で起きる） | `KINEMATIC_SIM` | `tests/test_exhibition_profile.py`（3 seeds） |
| 内部状態 6 種の回復可能性 | `SOFTWARE_VERIFIED` | `tests/test_internal_state_recovery.py`（24） |
| 一次反応 0.22s（BEHAVIOR_INTERNAL）/ 約 0.52s（END_TO_END_SIMULATED） | `KINEMATIC_SIM` / 推定 | HARDWARE_MEASURED は未 |
| 人が見た蛇らしさ・愛着・Fear | **HUMAN_EVALUATED = 0** | ユーザーが Pilot を実施するまで変わらない |

**正式な Risk**: 人物検出 5Hz（`person.detect_hz`）が展示の反応速度のボトルネックになりうる。
実機カメラ到着後に camera capture → detector → world state → behavior → command → visible response の
End-to-End latency を測る。

## 4.10 Floor Watch フェーズ 1 — 境界と契約（2026-09-25）

| 項目 | レベル | 根拠 |
|---|---|---|
| Task / Event API（schemas/*.json、5 Task・4 Event、frame `home`、floor_finding の不確かさ・危険度の内訳） | `SOFTWARE_VERIFIED` | `tests/test_task_event_api.py`（10）。スキーマ合格/不合格、版違い、map_version 違い、未知フィールド、安全設定の不在 |
| Loopback での往復（Task → 受理/拒否/冪等/stop 最優先 → Event）、Home AI 側モックが受け取る | `SOFTWARE_VERIFIED` | 同上。retain した safety_state が後からの購読に届く |
| フェーズ 1 追加確認 8〜11（operator_resume は MQTT から到達しない / safety_state の 2 s 周期送信と受け側時計での失効 / 正常終了の OFFLINE と再接続の上書き / stop と緊急停止の将来の分離を文書化） | `SOFTWARE_VERIFIED`（Loopback） | `tests/test_task_event_api_review.py`（3）+ `tests/test_task_event_api.py`（16） |
| 本物の MQTT ブローカーとの疎通 | 下の 4.11 を見る | |
| Home AI 本体 | 作らない（決定 14） | モックのみ |

## 4.11 Floor Watch フェーズ 2 — 画像処理（2026-09-25、`docs/floorwatch_phase2.md`）

| 項目 | レベル | 根拠 |
|---|---|---|
| 幾何（1.5mm → 21.3px、0.3mm → 4.3px、視野中心 71mm）と光の面の較正（名目からずれた面でも高さが戻る） | `SOFTWARE_VERIFIED` | `tests/test_floorwatch.py` |
| 合成画像（**基準床なし**、あごの斜め照明、継ぎ目を含む n = 70）: 設計値モード（f=1000）で patrol / inspect とも 98〜100%（95%CI 88〜100%。雑音で実行ごとに揺れる）、実機モード（UXGA f ≈ 1256 ASSUMED）で patrol 98% / inspect 100%・誤報 0%（0/28、95%CI 上限 12%）、線上の高さ ±1mm、鏡面 → height null + specular_break → metal_disc | **SIMULATED（合成画像。影も線も理想的なので楽観値）** | `tools/floorwatch_eval.py --synthetic` → `output/floorwatch_eval.md`、`tests/test_floorwatch.py`（9） |
| レビュー 2026-09-26 の 1〜7（高さ null + 理由 / 測れない = 出っ張り扱い / metal_disc 別枠 / 基準床なし / 撮影順と動き検出 / あご照明・影は奥 / 2 段評価と信頼区間 / 継ぎ目の合成） | `SOFTWARE_VERIFIED`（合成） | 同上 |
| 実写（手持ちカメラ、治具）での検出率・誤報率 | **未測定** | フェーズ 2 の完成条件。カメラ機種の回答待ち |
| 候補の種類の分類 | **未実装** | 実写データが揃ってから（合成で作ると過適合） |
| フェーズ 1 レビュー 1〜5（stop 最優先・待ち行列破棄・stop 前の Task 拒否・retain 拒否・LWT OFFLINE・危険物別枠・resolved は人だけ） | `SOFTWARE_VERIFIED` | `tests/test_task_event_api.py`（16） |
| 本物の MQTT（retain / LWT が keepalive の 1.5 倍で出る / 正常終了の OFFLINE / 再接続の上書き / QoS1 再送） | `SOFTWARE_VERIFIED`（本物の Mosquitto 2.1.2、2026-09-26。4 件: 黙ったクライアントの LWT は keepalive 2 s に対し 2〜5 s の窓で到着、ソケット断は即時、正常終了の OFFLINE は即時、再接続後の購読者は OFFLINE を見ない、QoS1 再送） | `tests/test_mqtt_live.py`（Mosquitto を 127.0.0.1 の一時ポートでサブプロセス起動。無ければ skip） |

## 4.12 Floor Watch フェーズ 3 — 自己位置（2026-09-26、`docs/floorwatch_phase3.md`）

| 項目 | レベル | 根拠 |
|---|---|---|
| 地図 `config/tags.yaml`（座標系 home、map_version）、推定器（予測・タグ補正・ゲート・IMU の磁北差）、開始条件が σ と IMU / オドメトリの健全性で決まる | `SOFTWARE_VERIFIED` | `tests/test_localization.py`（7） |
| 周回の閉ループで σ が正直（\|誤差\| ≤ 3σ が 98〜100%、滑り 5〜10%）、タグを見ずに走れる距離 ≈ 0.7〜1.1 m | **KINEMATIC_SIM 相当（SIMULATED）** | `tools/localization_sim.py` → `output/localization_sim.md` |
| AprilTag 検出 → 距離 3% / 方位 0.02 rad / 面の向き 0.06 rad | **合成画像** | `tests/test_localization.py` |
| 実カメラでの検出、実 IMU、実歩容の滑り、部屋のタグ配置 | **未測定** | フェーズ 4 の試験ツールで |

## 4.13 Floor Watch フェーズ 5 — 縦一本（2026-09-26、`docs/floorwatch_phase5.md`）

| 項目 | レベル | 根拠 |
|---|---|---|
| Home AI モック → inspect_point → 移動（KINEMATIC_SIM）→ 位置合わせ（前後の微調整 + 頭ヨーで線を地点へ）→ 撮影（合成）→ 判定 → floor_finding（推定姿勢 + σ、切り抜きだけ保存）→ モックが通知 | **SIMULATED（模擬の縦一本）** | `tests/test_floorwatch_slice.py`（3） |
| 開始条件（機体の停止・位置の確認待ち・σ・IMU・オドメトリ）で rejected、stop で aborted + HOLD、再開は operator_resume と機体側の開始操作の両方（人） | `SOFTWARE_VERIFIED` | 同上 |
| 実機での移動・撮影・照明制御・実タグ・実 IMU | **未実施** | フェーズ 4 の試験ツールと部品到着後 |

## 5. 書くときの約束

- 表・コメント・コミットメッセージで「確認済み」とだけ書かない。**上の4段のどれかを書く。**
- テレメトリは `source`（SIMULATION / HARDWARE）と `SIMULATED` フラグを持つ。
  **画面にも記録にもそのまま持ち回す。** 模擬の数値が実測として独り歩きしないようにするため。
- 実機で測ったら、この表と `docs/phase2_acceptance.md` §3 を**同時に**更新する。
  測定日・条件・測定器を書く。書けないものは `HARDWARE_VERIFIED` にしない。

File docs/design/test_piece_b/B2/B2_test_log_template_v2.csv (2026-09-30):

priority | trial_id | condition_t_mm | condition_c_mm | plate_T_mm(=c+t) | plate_how | object | floor | trial_no | result(enter/return/underrun/pushed_away) | video_file | notes
A | B2_c0_t0_1yen_flooring | 0 | 0 | 0 | none | 1yen | flooring | 1 |  | B2_c0_t0_1yen_flooring_01.mp4
A | B2_c0_t0_CR2032_flooring | 0 | 0 | 0 | none | CR2032 | flooring | 1 |  | B2_c0_t0_CR2032_flooring_01.mp4
A | B2_c0_t0_bead8_flooring | 0 | 0 | 0 | none | bead8 | flooring | 1 |  | B2_c0_t0_bead8_flooring_01.mp4
A | B2_c0_t0_cube10_flooring | 0 | 0 | 0 | none | cube10 | flooring | 1 |  | B2_c0_t0_cube10_flooring_01.mp4
A | B2_c0_t0p05_1yen_flooring | 0.05 | 0 | 0.05 | PET_or_shim_0.05 | 1yen | flooring | 1 |  | B2_c0_t0p05_1yen_flooring_01.mp4
A | B2_c0_t0p05_CR2032_flooring | 0.05 | 0 | 0.05 | PET_or_shim_0.05 | CR2032 | flooring | 1 |  | B2_c0_t0p05_CR2032_flooring_01.mp4
A | B2_c0_t0p05_bead8_flooring | 0.05 | 0 | 0.05 | PET_or_shim_0.05 | bead8 | flooring | 1 |  | B2_c0_t0p05_bead8_flooring_01.mp4
A | B2_c0_t0p05_cube10_flooring | 0.05 | 0 | 0.05 | PET_or_shim_0.05 | cube10 | flooring | 1 |  | B2_c0_t0p05_cube10_flooring_01.mp4
A | B2_c0_t0p1_1yen_flooring | 0.1 | 0 | 0.1 | see CORRECTION table | 1yen | flooring | 1 |  | B2_c0_t0p1_1yen_flooring_01.mp4
A | B2_c0_t0p1_CR2032_flooring | 0.1 | 0 | 0.1 | see CORRECTION table | CR2032 | flooring | 1 |  | B2_c0_t0p1_CR2032_flooring_01.mp4
A | B2_c0_t0p1_bead8_flooring | 0.1 | 0 | 0.1 | see CORRECTION table | bead8 | flooring | 1 |  | B2_c0_t0p1_bead8_flooring_01.mp4
A | B2_c0_t0p1_cube10_flooring | 0.1 | 0 | 0.1 | see CORRECTION table | cube10 | flooring | 1 |  | B2_c0_t0p1_cube10_flooring_01.mp4
A | B2_c0_t0p2_1yen_flooring | 0.2 | 0 | 0.2 | see CORRECTION table | 1yen | flooring | 1 |  | B2_c0_t0p2_1yen_flooring_01.mp4
A | B2_c0_t0p2_CR2032_flooring | 0.2 | 0 | 0.2 | see CORRECTION table | CR2032 | flooring | 1 |  | B2_c0_t0p2_CR2032_flooring_01.mp4
A | B2_c0_t0p2_bead8_flooring | 0.2 | 0 | 0.2 | see CORRECTION table | bead8 | flooring | 1 |  | B2_c0_t0p2_bead8_flooring_01.mp4
A | B2_c0_t0p2_cube10_flooring | 0.2 | 0 | 0.2 | see CORRECTION table | cube10 | flooring | 1 |  | B2_c0_t0p2_cube10_flooring_01.mp4
A | B2_c0_t0p5_1yen_flooring | 0.5 | 0 | 0.5 | see CORRECTION table | 1yen | flooring | 1 |  | B2_c0_t0p5_1yen_flooring_01.mp4
A | B2_c0_t0p5_CR2032_flooring | 0.5 | 0 | 0.5 | see CORRECTION table | CR2032 | flooring | 1 |  | B2_c0_t0p5_CR2032_flooring_01.mp4
A | B2_c0_t0p5_bead8_flooring | 0.5 | 0 | 0.5 | see CORRECTION table | bead8 | flooring | 1 |  | B2_c0_t0p5_bead8_flooring_01.mp4
A | B2_c0_t0p5_cube10_flooring | 0.5 | 0 | 0.5 | see CORRECTION table | cube10 | flooring | 1 |  | B2_c0_t0p5_cube10_flooring_01.mp4
A | B2_c0_t1_1yen_flooring | 1.0 | 0 | 1.0 | see CORRECTION table | 1yen | flooring | 1 |  | B2_c0_t1_1yen_flooring_01.mp4
A | B2_c0_t1_CR2032_flooring | 1.0 | 0 | 1.0 | see CORRECTION table | CR2032 | flooring | 1 |  | B2_c0_t1_CR2032_flooring_01.mp4
A | B2_c0_t1_bead8_flooring | 1.0 | 0 | 1.0 | see CORRECTION table | bead8 | flooring | 1 |  | B2_c0_t1_bead8_flooring_01.mp4
A | B2_c0_t1_cube10_flooring | 1.0 | 0 | 1.0 | see CORRECTION table | cube10 | flooring | 1 |  | B2_c0_t1_cube10_flooring_01.mp4
B | B2_c0_t0_1yen_mat | 0 | 0 | 0 | none | 1yen | mat | 1 |  | B2_c0_t0_1yen_mat_01.mp4
B | B2_c0_t0_1yen_carpet | 0 | 0 | 0 | none | 1yen | carpet | 1 |  | B2_c0_t0_1yen_carpet_01.mp4
B | B2_c0_t0_CR2032_mat | 0 | 0 | 0 | none | CR2032 | mat | 1 |  | B2_c0_t0_CR2032_mat_01.mp4
B | B2_c0_t0_CR2032_carpet | 0 | 0 | 0 | none | CR2032 | carpet | 1 |  | B2_c0_t0_CR2032_carpet_01.mp4
B | B2_c0_t0_bead8_mat | 0 | 0 | 0 | none | bead8 | mat | 1 |  | B2_c0_t0_bead8_mat_01.mp4
B | B2_c0_t0_bead8_carpet | 0 | 0 | 0 | none | bead8 | carpet | 1 |  | B2_c0_t0_bead8_carpet_01.mp4
B | B2_c0_t0_cube10_mat | 0 | 0 | 0 | none | cube10 | mat | 1 |  | B2_c0_t0_cube10_mat_01.mp4
B | B2_c0_t0_cube10_carpet | 0 | 0 | 0 | none | cube10 | carpet | 1 |  | B2_c0_t0_cube10_carpet_01.mp4
B | B2_c0p3_t0_1yen_flooring | 0 | 0.3 | 0.3 | see CORRECTION table | 1yen | flooring | 1 |  | B2_c0p3_t0_1yen_flooring_01.mp4
B | B2_c0p3_t0_1yen_mat | 0 | 0.3 | 0.3 | see CORRECTION table | 1yen | mat | 1 |  | B2_c0p3_t0_1yen_mat_01.mp4
B | B2_c0p3_t0_1yen_carpet | 0 | 0.3 | 0.3 | see CORRECTION table | 1yen | carpet | 1 |  | B2_c0p3_t0_1yen_carpet_01.mp4
B | B2_c0p3_t0_CR2032_flooring | 0 | 0.3 | 0.3 | see CORRECTION table | CR2032 | flooring | 1 |  | B2_c0p3_t0_CR2032_flooring_01.mp4
B | B2_c0p3_t0_CR2032_mat | 0 | 0.3 | 0.3 | see CORRECTION table | CR2032 | mat | 1 |  | B2_c0p3_t0_CR2032_mat_01.mp4
B | B2_c0p3_t0_CR2032_carpet | 0 | 0.3 | 0.3 | see CORRECTION table | CR2032 | carpet | 1 |  | B2_c0p3_t0_CR2032_carpet_01.mp4
B | B2_c0p3_t0_bead8_flooring | 0 | 0.3 | 0.3 | see CORRECTION table | bead8 | flooring | 1 |  | B2_c0p3_t0_bead8_flooring_01.mp4
B | B2_c0p3_t0_bead8_mat | 0 | 0.3 | 0.3 | see CORRECTION table | bead8 | mat | 1 |  | B2_c0p3_t0_bead8_mat_01.mp4
B | B2_c0p3_t0_bead8_carpet | 0 | 0.3 | 0.3 | see CORRECTION table | bead8 | carpet | 1 |  | B2_c0p3_t0_bead8_carpet_01.mp4
B | B2_c0p3_t0_cube10_flooring | 0 | 0.3 | 0.3 | see CORRECTION table | cube10 | flooring | 1 |  | B2_c0p3_t0_cube10_flooring_01.mp4
B | B2_c0p3_t0_cube10_mat | 0 | 0.3 | 0.3 | see CORRECTION table | cube10 | mat | 1 |  | B2_c0p3_t0_cube10_mat_01.mp4
B | B2_c0p3_t0_cube10_carpet | 0 | 0.3 | 0.3 | see CORRECTION table | cube10 | carpet | 1 |  | B2_c0p3_t0_cube10_carpet_01.mp4
B | B2_c1_t0_1yen_flooring | 0 | 1.0 | 1.0 | see CORRECTION table | 1yen | flooring | 1 |  | B2_c1_t0_1yen_flooring_01.mp4
B | B2_c1_t0_1yen_mat | 0 | 1.0 | 1.0 | see CORRECTION table | 1yen | mat | 1 |  | B2_c1_t0_1yen_mat_01.mp4
B | B2_c1_t0_1yen_carpet | 0 | 1.0 | 1.0 | see CORRECTION table | 1yen | carpet | 1 |  | B2_c1_t0_1yen_carpet_01.mp4
B | B2_c1_t0_CR2032_flooring | 0 | 1.0 | 1.0 | see CORRECTION table | CR2032 | flooring | 1 |  | B2_c1_t0_CR2032_flooring_01.mp4
B | B2_c1_t0_CR2032_mat | 0 | 1.0 | 1.0 | see CORRECTION table | CR2032 | mat | 1 |  | B2_c1_t0_CR2032_mat_01.mp4
B | B2_c1_t0_CR2032_carpet | 0 | 1.0 | 1.0 | see CORRECTION table | CR2032 | carpet | 1 |  | B2_c1_t0_CR2032_carpet_01.mp4
B | B2_c1_t0_bead8_flooring | 0 | 1.0 | 1.0 | see CORRECTION table | bead8 | flooring | 1 |  | B2_c1_t0_bead8_flooring_01.mp4
B | B2_c1_t0_bead8_mat | 0 | 1.0 | 1.0 | see CORRECTION table | bead8 | mat | 1 |  | B2_c1_t0_bead8_mat_01.mp4
B | B2_c1_t0_bead8_carpet | 0 | 1.0 | 1.0 | see CORRECTION table | bead8 | carpet | 1 |  | B2_c1_t0_bead8_carpet_01.mp4
B | B2_c1_t0_cube10_flooring | 0 | 1.0 | 1.0 | see CORRECTION table | cube10 | flooring | 1 |  | B2_c1_t0_cube10_flooring_01.mp4
B | B2_c1_t0_cube10_mat | 0 | 1.0 | 1.0 | see CORRECTION table | cube10 | mat | 1 |  | B2_c1_t0_cube10_mat_01.mp4
B | B2_c1_t0_cube10_carpet | 0 | 1.0 | 1.0 | see CORRECTION table | cube10 | carpet | 1 |  | B2_c1_t0_cube10_carpet_01.mp4
B | B2_c0_t0p05_1yen_mat | 0.05 | 0 | 0.05 | PET_or_shim_0.05 | 1yen | mat | 1 |  | B2_c0_t0p05_1yen_mat_01.mp4
B | B2_c0_t0p05_1yen_carpet | 0.05 | 0 | 0.05 | PET_or_shim_0.05 | 1yen | carpet | 1 |  | B2_c0_t0p05_1yen_carpet_01.mp4
B | B2_c0_t0p05_CR2032_mat | 0.05 | 0 | 0.05 | PET_or_shim_0.05 | CR2032 | mat | 1 |  | B2_c0_t0p05_CR2032_mat_01.mp4
B | B2_c0_t0p05_CR2032_carpet | 0.05 | 0 | 0.05 | PET_or_shim_0.05 | CR2032 | carpet | 1 |  | B2_c0_t0p05_CR2032_carpet_01.mp4
B | B2_c0_t0p05_bead8_mat | 0.05 | 0 | 0.05 | PET_or_shim_0.05 | bead8 | mat | 1 |  | B2_c0_t0p05_bead8_mat_01.mp4
B | B2_c0_t0p05_bead8_carpet | 0.05 | 0 | 0.05 | PET_or_shim_0.05 | bead8 | carpet | 1 |  | B2_c0_t0p05_bead8_carpet_01.mp4
B | B2_c0_t0p05_cube10_mat | 0.05 | 0 | 0.05 | PET_or_shim_0.05 | cube10 | mat | 1 |  | B2_c0_t0p05_cube10_mat_01.mp4
B | B2_c0_t0p05_cube10_carpet | 0.05 | 0 | 0.05 | PET_or_shim_0.05 | cube10 | carpet | 1 |  | B2_c0_t0p05_cube10_carpet_01.mp4
B | B2_c0p3_t0p05_1yen_flooring | 0.05 | 0.3 | 0.35 | PET_or_shim_0.05(+pad c) | 1yen | flooring | 1 |  | B2_c0p3_t0p05_1yen_flooring_01.mp4
B | B2_c0p3_t0p05_1yen_mat | 0.05 | 0.3 | 0.35 | PET_or_shim_0.05(+pad c) | 1yen | mat | 1 |  | B2_c0p3_t0p05_1yen_mat_01.mp4
B | B2_c0p3_t0p05_1yen_carpet | 0.05 | 0.3 | 0.35 | PET_or_shim_0.05(+pad c) | 1yen | carpet | 1 |  | B2_c0p3_t0p05_1yen_carpet_01.mp4
B | B2_c0p3_t0p05_CR2032_flooring | 0.05 | 0.3 | 0.35 | PET_or_shim_0.05(+pad c) | CR2032 | flooring | 1 |  | B2_c0p3_t0p05_CR2032_flooring_01.mp4
B | B2_c0p3_t0p05_CR2032_mat | 0.05 | 0.3 | 0.35 | PET_or_shim_0.05(+pad c) | CR2032 | mat | 1 |  | B2_c0p3_t0p05_CR2032_mat_01.mp4
B | B2_c0p3_t0p05_CR2032_carpet | 0.05 | 0.3 | 0.35 | PET_or_shim_0.05(+pad c) | CR2032 | carpet | 1 |  | B2_c0p3_t0p05_CR2032_carpet_01.mp4
B | B2_c0p3_t0p05_bead8_flooring | 0.05 | 0.3 | 0.35 | PET_or_shim_0.05(+pad c) | bead8 | flooring | 1 |  | B2_c0p3_t0p05_bead8_flooring_01.mp4
B | B2_c0p3_t0p05_bead8_mat | 0.05 | 0.3 | 0.35 | PET_or_shim_0.05(+pad c) | bead8 | mat | 1 |  | B2_c0p3_t0p05_bead8_mat_01.mp4
B | B2_c0p3_t0p05_bead8_carpet | 0.05 | 0.3 | 0.35 | PET_or_shim_0.05(+pad c) | bead8 | carpet | 1 |  | B2_c0p3_t0p05_bead8_carpet_01.mp4
B | B2_c0p3_t0p05_cube10_flooring | 0.05 | 0.3 | 0.35 | PET_or_shim_0.05(+pad c) | cube10 | flooring | 1 |  | B2_c0p3_t0p05_cube10_flooring_01.mp4
B | B2_c0p3_t0p05_cube10_mat | 0.05 | 0.3 | 0.35 | PET_or_shim_0.05(+pad c) | cube10 | mat | 1 |  | B2_c0p3_t0p05_cube10_mat_01.mp4
B | B2_c0p3_t0p05_cube10_carpet | 0.05 | 0.3 | 0.35 | PET_or_shim_0.05(+pad c) | cube10 | carpet | 1 |  | B2_c0p3_t0p05_cube10_carpet_01.mp4
B | B2_c1_t0p05_1yen_flooring | 0.05 | 1.0 | 1.05 | PET_or_shim_0.05(+pad c) | 1yen | flooring | 1 |  | B2_c1_t0p05_1yen_flooring_01.mp4
B | B2_c1_t0p05_1yen_mat | 0.05 | 1.0 | 1.05 | PET_or_shim_0.05(+pad c) | 1yen | mat | 1 |  | B2_c1_t0p05_1yen_mat_01.mp4
B | B2_c1_t0p05_1yen_carpet | 0.05 | 1.0 | 1.05 | PET_or_shim_0.05(+pad c) | 1yen | carpet | 1 |  | B2_c1_t0p05_1yen_carpet_01.mp4
B | B2_c1_t0p05_CR2032_flooring | 0.05 | 1.0 | 1.05 | PET_or_shim_0.05(+pad c) | CR2032 | flooring | 1 |  | B2_c1_t0p05_CR2032_flooring_01.mp4
B | B2_c1_t0p05_CR2032_mat | 0.05 | 1.0 | 1.05 | PET_or_shim_0.05(+pad c) | CR2032 | mat | 1 |  | B2_c1_t0p05_CR2032_mat_01.mp4
B | B2_c1_t0p05_CR2032_carpet | 0.05 | 1.0 | 1.05 | PET_or_shim_0.05(+pad c) | CR2032 | carpet | 1 |  | B2_c1_t0p05_CR2032_carpet_01.mp4
B | B2_c1_t0p05_bead8_flooring | 0.05 | 1.0 | 1.05 | PET_or_shim_0.05(+pad c) | bead8 | flooring | 1 |  | B2_c1_t0p05_bead8_flooring_01.mp4
B | B2_c1_t0p05_bead8_mat | 0.05 | 1.0 | 1.05 | PET_or_shim_0.05(+pad c) | bead8 | mat | 1 |  | B2_c1_t0p05_bead8_mat_01.mp4
B | B2_c1_t0p05_bead8_carpet | 0.05 | 1.0 | 1.05 | PET_or_shim_0.05(+pad c) | bead8 | carpet | 1 |  | B2_c1_t0p05_bead8_carpet_01.mp4
B | B2_c1_t0p05_cube10_flooring | 0.05 | 1.0 | 1.05 | PET_or_shim_0.05(+pad c) | cube10 | flooring | 1 |  | B2_c1_t0p05_cube10_flooring_01.mp4
B | B2_c1_t0p05_cube10_mat | 0.05 | 1.0 | 1.05 | PET_or_shim_0.05(+pad c) | cube10 | mat | 1 |  | B2_c1_t0p05_cube10_mat_01.mp4
B | B2_c1_t0p05_cube10_carpet | 0.05 | 1.0 | 1.05 | PET_or_shim_0.05(+pad c) | cube10 | carpet | 1 |  | B2_c1_t0p05_cube10_carpet_01.mp4
B | B2_c0_t0p1_1yen_mat | 0.1 | 0 | 0.1 | see CORRECTION table | 1yen | mat | 1 |  | B2_c0_t0p1_1yen_mat_01.mp4
B | B2_c0_t0p1_1yen_carpet | 0.1 | 0 | 0.1 | see CORRECTION table | 1yen | carpet | 1 |  | B2_c0_t0p1_1yen_carpet_01.mp4
B | B2_c0_t0p1_CR2032_mat | 0.1 | 0 | 0.1 | see CORRECTION table | CR2032 | mat | 1 |  | B2_c0_t0p1_CR2032_mat_01.mp4
B | B2_c0_t0p1_CR2032_carpet | 0.1 | 0 | 0.1 | see CORRECTION table | CR2032 | carpet | 1 |  | B2_c0_t0p1_CR2032_carpet_01.mp4
B | B2_c0_t0p1_bead8_mat | 0.1 | 0 | 0.1 | see CORRECTION table | bead8 | mat | 1 |  | B2_c0_t0p1_bead8_mat_01.mp4
B | B2_c0_t0p1_bead8_carpet | 0.1 | 0 | 0.1 | see CORRECTION table | bead8 | carpet | 1 |  | B2_c0_t0p1_bead8_carpet_01.mp4
B | B2_c0_t0p1_cube10_mat | 0.1 | 0 | 0.1 | see CORRECTION table | cube10 | mat | 1 |  | B2_c0_t0p1_cube10_mat_01.mp4
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

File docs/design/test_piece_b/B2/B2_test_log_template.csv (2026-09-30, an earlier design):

condition_t_mm | condition_c_mm | object | floor | result(enter/return/underrun/pushed_away/pinched) | notes
0 | 0 | 1yen | floor
0 | 0 | CR2032 | floor
0 | 0 | bead | floor
0 | 0 | cube | floor
0.1 | 0 | 1yen | floor
0.2 | 0 | 1yen | floor
0.5 | 0 | 1yen | floor
1.0 | 0 | 1yen | floor
0 | 0.3 | 1yen | floor
0 | 1.0 | 1yen | floor

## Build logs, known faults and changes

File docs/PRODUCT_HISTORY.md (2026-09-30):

# PRODUCT_HISTORY — Serpens の軌跡（事細かな経緯）

作成 2026-10-01（Design Agent）。**このファイルは追記専用の年表**。プロダクトが「いつ・何を・なぜ・どの数字で」進んだかを、あとから誰（人・AI）が読んでも辿れるように残す。
出どころ: `git log`（全ブランチ）、`ai-shared/integration-log.md`（ENTRY）、`ai-shared/design-state.md`、`engineering-state.md`、`REQUESTS.md`、`HARDWARE_TODO.md`、`agent/DECISIONS.md`、`PRODUCT.md`、User の指示。
**数値には出典を付ける**（実測 / シミュレーション / prior）。**5.7 N・0.25 N·m は暫定（SAFETY_UNVERIFIED）。安全・合格の語は、実測で確かめたものにしか使わない。** 約 20 倍の注意（下の §1）は、現行 CAD の状態が変わるまで書き続ける。

## 0. このファイルの使い方・更新ルール（これからもこうする）

- **1 回の作業のまとまり（ENTRY を書くたび）に、§9「更新ログ」へ 1 節を足す**。書くこと: 日付・時刻、誰（Design / Engineering / User）、依頼（原文の要点）、やったこと、出した数値（出典つき）、**訂正・撤回**、決まったこと（誰が）、出したファイル（パス）、コミット、残ったこと・待ち。
- **§1「現在地」と §6「数値の推移」と §7「訂正・撤回の記録」も、変わったら書き換える**（ここだけは最新に保つ。履歴は §9 に残る）。
- 結果が悪くても書く（後付けの調整をしない）。間違いは消さずに「訂正」として足す。
- 相手（Engineering / Design）の領分は、相手の ENTRY を引用して書く。自分の推測を事実として書かない。
- 日付の区切りは JST（git のコミット時刻）。

## 1. 現在地（2026-10-01 02:30 時点）

**プロダクト**: Serpens ＝ 床を巡回して、子どもが飲み込みそうな小物を見つけ、地図に出して知らせる**ペット型ヘビロボット**（Home AI の入口）。第一号機は **Floor Watch MVP**（5 サーボ: J1 首 pitch、J2〜J5 yaw。車輪なし）。**律速はハードウェア（サーボ実機ゼロ）**。

**先頭の注意（約 20 倍）**: KNUCKLE DRUM 後も、まっすぐ比で約 20 倍（18〜24 倍）のすき間（幅 5〜12.5 mm・深さ 8 mm 以上の届くすき間）の体積が残る（まっすぐ 124 mm³、曲げた姿勢 2250〜2939 mm³）。背板の層（約 1020 mm³/姿勢）は現行 CAD では未解決のまま。5.7 N・0.25 N·m は暫定（SAFETY_UNVERIFIED）。

| 領域 | 状態（出典）|
|---|---|
| 制御・安全・API・画像処理・自己位置 | 模擬で縦 1 本が通る（SOFTWARE/MOCK）。テスト 563 passed / 1 skipped（`agent/engineering-vision-sim`、2026-09-29）。**実機は未検証** |
| J1（頭ピッチ）| 範囲 **θ_E −4〜+3°**（PROVISIONAL。Engineering 最適化 E-0011、prior）。作業窓 −2〜+1°。機械ストッパー = 鋼ダウエル φ3 + TPU パッド。覆い **案 A を User が採用**。強制は設定で**既定オフ**（`neck.floor_watch_enforce`）。**HT-001（実機の符号）が先** |
| 頭 E3 | Design の統合版 v2（かわいいデフォルメ）を Fusion に保存。あご −32.7%。**質量は殻でも 137〜234 g で、予算 90 g を超える**（CAD_CONCEPT、Design の課題）|
| 取り込み機構 | 開放底フード + 漏斗 + ゲート + フード昇降（s = 4 mm、TPU 板ばね耳、上げる力 約 1.2 N（prior））。段差 t ≥ 0.002 mm で 0%（シミュ）。**実物の観察（B2）は印刷待ち** |
| 試験片・印刷 | `docs/design/print_all/`（P0 B2 → P1 TPU クーポン・ダウエル → P2 覆い・肉球 → P3 KNUCKLE）。**印刷は未実施** |
| 頭のセンサー基板（試作、T4/T6 用） | KiCad の `serpens/head-sensor-board/`（別 git、`github.com/hattoir/head-sensor-board`（private））。**Stage 3（外形 40×25 mm と部品配置、commit 756b482。DRC は未配線以外 0 件、40×25 が下限で余裕ゼロ）まで。配線・ガーバーは未着手（ToF 小基板のピン配置が未確認）**。3V3 だけでは NSSW157T は 80 mA 時の約 30 %（8.5〜38.8 mA）（計算、ENTRY-K-0001）。運用: 3V3 で Wi-Fi 送信・撮影・LED 100 %・ToF ピークを同時にしない（ENTRY-K-0002）|
| 待ち | 印刷・実機: HT-001 / 007 / 008 / 009 / 012 / 013。Engineering: 頭の質量予算の扱い、ENTRY-K-0001・K-0002（R-020）。User: 印刷と買うものの承認、ToF 小基板の現物のピン配置 |

## 2. 年表（日ごと）

### 2026-09-12 〜 09-14 — EX-1（展示機 9 軸）の基盤（Engineering、1 人の Claude が STEP 順に）
- 09-12: **STEP1 環境構築** → **STEP2 サーボ抽象層とモック** → **STEP3 歩容エンジン・姿勢・アニメーター** → **STEP4 2D シミュレータ**（レビュー回答を反映）→ **STEP4.5 Sim-to-Real 校正の器** → **STEP5 知覚（ArUco・ホモグラフィ・人物追跡）** → **STEP6 内部状態と行動**（安全割り込み・展示レイアウトの変更を反映）→ **STEP7 展示用 GUI（4 分割）** → YOLO の重みを配置しオフライン起動を検証 → **STEP8 実機用の対話式ツール `servo_setup.py`**。（`4293c29` … `5f00df6`）
- 09-13: Phase1（実機接続の配線・停止の分離・終了処理）、**Phase2: PC⇄ESP32 駆動リンク（機体側 watchdog と緊急停止ラッチ）**（`7577e35`、`06676e9`）。
- 09-14: 製品憲章との対応表、関節数の決め打ちを外す。駆動リンクに BODY（胴体姿勢）と TORQUE（脱力）。**安全の絶対値（構想設計書 16 章）を設定・実装・テストへ**。**Phase3: 行動 → 駆動リンク → 機体を 1 本に繋いだ（`--robot link`）**。DECISIONS: 制御ループ例外時は fault の公開を緊急停止の後に / 通信断は「とぐろ」でなくその場で保持 / ARM は人の開始操作だけ / トルク比は安全上限に対する割合 / Autonomous Product Development OS を導入 / フォルダを `C:/2026/serpens` へ移さない。

### 2026-09-15 〜 09-16 — 機体の状態・摩擦・MuJoCo・可動域（Engineering）
- 09-15: 可動域を 3 段にし CAD R03（±64°）へ。**Virtual ESP32 を 7 状態化**、仮想サーボバス・テレメトリ v2。故障注入を 1 か所に集約、検証レベルを文書化。Belly・摩擦プロファイル・歩容パラメータ・サーボ版数を config 化。GUI に関節ペイン。SimulatedSnake / RealSnake、Phase 3B の物理エンジン選定（MuJoCo 第一候補）。
- 09-16: **Stage B/C** 可動域を意味別に分け C044 プロファイルへ（サーボは STS3215-C044、トルクは 4 つに分ける）。**Stage D** 不変条件をテストで固定・fault 公開の race 修正。**Stage E** ファームのコンパイル検証（書き込みなし）。**Stage F〜N** MuJoCo 導入と閉ループ、**再起動後の自動再走行の穴を塞いだ（ARM に boot_id）**。Stage I 歩容掃引。ELECTRICAL_SAFETY_GATE を実機自律走行の開始条件に。**Phase 4** 模擬画像の Vision で閉ループ、見失い時は保持し自動再開しない。

### 2026-09-18 〜 09-21 — 行動の質・動きの語彙・評価（Engineering）
- 09-18: 実画像経路 CameraObserver、見失い後の位置確認、制御周期の実測、電子系の設計案。**Bug-1〜3**（Stress の飽和、Energy に疲れ、効用ノイズ）。PATROL を stop-and-go に。一次反応（150〜250 ms の目の点灯 + J8 のピクッ）、舌のちらつき、呼吸に尾→頭の位相勾配、視線の時定数を gaze 研究へ、**威嚇に見える姿勢を演出から外す**、予備動作・減衰振動、接近を忍び寄り波形に。
- 09-21: **primitives（語彙）/ grammar（文法・config）/ locomotion に分離**、撫での 3 段応答。評価指標 5 種（LDJ・静止率・可視波数・一次反応・GAR）。内部状態を 6 種に。**EXHIBITION profile**（60〜90 秒の体験弧）。**Human Perception Pilot** の準備（6/8/10 Yaw の比較）。DECISIONS: Human Evaluation を最優先ゲートに。

### 2026-09-25 〜 09-27 — 方向転換: Floor Watch（Engineering）
- 09-25: **床見守り機ブリーフ**を受け、実装前の 3 点・4 点（質問リスト・snake.yaml と MQTT 形式の案・フェーズ 1 計画）。**Floor Watch フェーズ 1: Home AI ↔ Serpens の Task / Event API**（スキーマ・検証器・Loopback ブローカー）。レビュー対応: **stop は何があっても受理**、stop/FAULT で待ち行列破棄、LWT で OFFLINE。フェーズ 2: 4 枚（全消灯/通常/斜め/線光）から出っ張りを判定（合成画像）。
- 09-26: レビュー対応（基準床なし・高さ null・metal_disc・あご照明・2 段評価・Mosquitto 実試験）、フェーズ 3 **自己位置**（AprilTag + IMU + 歩容オドメトリ）、フェーズ 5 **縦一本を模擬でつなぐ**（inspect_point → 移動 → 位置合わせ → 撮影 → 判定 → floor_finding → 通知）。**PRODUCT.md を作成**（MVP = 5 サーボ、やらないこと: 口でくわえて運ぶ・レーザー・画像を家の外へ・MQTT で関節角）。
- 09-27: カメラは解像度ごとに f（床見 UXGA / タグ探し VGA、ASSUMED）、減速比は暫定 1:345。

### 2026-09-29 — 複数 Agent の並行運用が始まる（Engineering 3〜4 本 + Design）
- **Engineering**: MuJoCo の床見基準（`69b7179` → revert して整理）、H0 摩擦クーポン・H1 C044 関節・H2 センサー頭の Hardware Gap シミュレーション、**MQTT の safety_state retain の race 修正（DEC-SERPENS-0001）**、**C044 のトルク基準を最新の資料値へ、レジスタ比 0.287 → 0.167**、合成視覚 VIS-0002〜0009（pose_from_line、点光源 h/r³、平場補正、J1 の頭の高さ保持）、floorwatch の検出の修正（線だけの誤報、絨毯の誤報、影の統合の回帰試験）、**CSAR の実行条件**（子どもが近いとき）、`Task.child_near`、**指の挟み込み基準を「5 mm 未満 か 25 mm 以上」に**（`097ed77`）、**yaw 合計 145°（4 層）・機械式トルクリミッター設計値・暫定の接触しきい値**（`6a9fd2e`）、テスト 530 → 563 passed。
- **Design（初登場 01:50）**: `dd9369b` **SD-01「Bean 頭 + 同心ナックル」+ CSAR** の探索。Run DESIGN-2026-09-29-01。**User 判断 USER-DEC-SERPENS-DESIGN-0001**（§4）。Fusion が何度も応答停止 → **Recovery copy** 方針。SD-01A〜E の比較、SD-01E → E2（目 35° 外向き・内側の glint・小さい鼻・クリームの眉）→ **E3（口の線）**、J1 の頭–首の入れ子 **VISOR**（交差 0）、ライン光の位置（眉）、照明 40 → 15 倍（近）/ 33 → 11 倍（遠）、6 本目の比較（Head Yaw / Body Yaw）、チンシールド、ENTRY-0011（電装と同心ナックルの衝突）。**USER-DEC-0002（CSAR の撮影）、0003（対象 3 歳未満・Safety Envelope 6 歳以下・yaw 合計 145°）、0004（Head Yaw と 145°）**。Design の Head Yaw 提案 ±30°。
- **取り込み機構（scoop）の探索が始まる**（`32e73e4`, 15:51）: ヘビの頭のすくい + ふたを MuJoCo で。**ブリーフの範囲では成功率 0%**。

### 2026-09-30 昼 — 取り込み・すき間・KNUCKLE DRUM（Engineering + Design）
- 09:33〜13:23 **scoop**: 短いランプ・くちばし型スイーパー（144 + 48 設計、N=30、感度）→ **開放底フード + ゲートがベースライン**（N=30、段差の除去 ablation、跨ぎの分類）、機構 A〜G（横スイーパー・ローラーベルト・ブラシ・カップ・フック・止め・漏斗）。
- 09:54 **Design HEAD INTAKE STUDY 01**（ENTRY-D-0002）: 卵の頭には入らない（空間の 42〜66% が外）/ Bean 頭なら約 92% 入る / スキッド・下向き ToF と衝突。
- 11:06 **すき間チェック**（ENTRY-D-0003、OPEN-014）: STL ボクセル 0.5 mm、6 姿勢。静止の実欠陥（背板の尖り・頭巾の溝・ポケット・J2 の低い板・尾の刃）を CAD で直す。**曲げた姿勢で「全角度で 5〜12 mm のすき間なし」は成り立たない**（脇の V）。ボクセル化の負の切片バグを直した。
- 11:43 **safety**: 脇の V は**カバーで対処（主）・トルク制限は補助**（E-0005）。
- 13:23 **KNUCKLE DRUM**（ENTRY-D-0004）: 関節の玉の脇を完全な円柱（R46、J2 は R34）に戻す → 胴の層のすき間 約 90% 減（p1 6807 → 2558）。頭の下の後ろの埋め物で p0 172 → 2 mm³。FLANK SKIRT のフラップは**効かず**（すき間が増えた）。**「V は形で消せない」の主張は撤回**（D-0004）。
- 14:01 **safety**（E-0006）: Design の接触半径から J3〜J5 の許容トルク 約 0.25 N·m（0.45 の上限に対し OPEN）、J1 の範囲 −5〜+10° を提案。**User: KNUCKLE DRUM を承認**（14:14）→ 試験片（R46/R34、ゲージ）、試験片 B1（漏斗つきフード）、質量（中実 61.1 g / 中空 55.8 g）。**報告の冒頭に「約 20 倍」を書き続ける規則**。
- 14:28 `00_STATUS/`（進捗・User の To-do・Engineering への依頼・ファイルの地図）。15:32 scoop 追加検討（公差・受け身カーテン・スカート + 凸凹床・ゲート力）。15:35 safety: KNUCKLE DRUM の質量（PROPOSED）、**J7 の静的トルクを訂正（0.204 N·m）**。

### 2026-09-30 午後〜夜 — B2・頭への統合・口の前の配置（Design、User の指示に順次）
- 15:52 **試験片 B2**（段差 t とすき間 c を独立）、**HEAD INTAKE on E3**（フード空洞 33.75 cm³ のうちあご 25.0 cm³ を掘る。ToF 下向き 648 mm³ 衝突）、**背板の層の 2 案**（(a) DRUM-FULL / (b) 同心ドーム）、J1 ピッチ −5〜+10°（ENTRY-D-0006）。
- 18:35 **口の前に床に触れる部品を置かない**（禁止域に入る部品 15,290 mm³ → 0）、**c は床から**（シミュのコードを読んで確認、**B2 の板の位置と c の基準は Design の誤りで訂正**）、J1 取り込み窓、照明再計算（斜めを口の前の角へ: 15 → 35 倍）（D-0007）。Fusion 切断で CAD 未変更。
- 19:11 **D-0008**: J1 分解能 0.0879°/ステップ（前縁 0.083 mm）、**受動の柔らかさは成り立たない**（バックドライブ > 頭の重力モーメント）、VL53L1X は 4 cm 未満は不正確・±20〜25 mm で数 mm は測れない、斜め LED は**横スキッド前端**が最良（巡回 0.94）。
- 19:13 scoop: 段差 0.002 mm で 0% が理想化か（面取り・粗さ・ソルバ）を確認。**0.05 mm だけが生き残る 1 点**（面取り 10/20° + 粗さ ±0.1、44〜59%、仮説は未検証）。
- 19:44 **D-0009**: B2 の印刷リスト（PLA、0.20、エレファントフット補正）、t = 0.05 の貼り方、記録表 v2、**Engineering 回答を「Design の見積もり」に位置づけ直し**、フード昇降（cloche drop）の概念（s 5/8/10 を あご・カメラ・J1 サーボとの干渉体積で比較）。
- 20:03〜20:12 **Engineering**: H1/H2（J1 の不感帯・バックラッシ・押す力の試験、床接触の較正、ToF の崖判定）、**フード昇降の安全の枠組み**（自重 0.112 N、上げる側 ≤ 2.8 N、すき間 4 mm 以下）、薄いフィルムは 0%・**フード昇降は 100%**。
- 20:22 **D-0010（Fusion 復帰）**: 口の前の配置・フード昇降・J1 カバー + ストッパーを CAD に。**重大な訂正: CAD の姿勢ラベルは + が頭を下げる**（前の文書は逆）→ 範囲の端は −5° = 401、+10° = 1562 mm³（前に 601 / 2062 と書いたものは入れ替わり）。上の輪の覆いで −5° 401 → 29。
- 20:25 **Engineering E-0009**: 符号は Engineering が + = 上げ（実機は未確認 → HT-001）、ストッパーの荷重（PLA ピン 約 21 N で不足 → 鋼ダウエル）。
- 20:29 **D-0011**: User の許可（「組み替えていい」「デフォルメ調でかわいく愛らしい感じ」）で**頭 E3 統合版 v1**（大きな黒い目、セージの頭、アイボリーのあご、クリームのフード、丸いスキッド、ピンクの頬レンズ）。あご −56.5 cm³（−34%）。

### 2026-09-30 夜 — 自律運用・J1 最適化・覆い・ストッパー
- 21:01 **Engineering E-0010: 自律運用の仕組み**（AUTONOMY / REQUESTS / HARDWARE_TODO。User に聞くのは Design の見た目・形だけ。緩める安全変更は PROPOSED。`.ai/LOCAL_RULES.md` と食い違う「緩めてよい」は厳しい側を採用）。
- 21:17 **E-0011: J1 の範囲・ストッパー荷重の最適化**（パレート・膝・モンテカルロ）→ **範囲 [−4, +3]**（膝 = +3°）、作業窓 −2〜+1°、窓の端の手前 ≤ 40 °/s、**鋼ダウエル φ3 + TPU パッド**。取り込みは c ≤ 1.0 mm で 100%（MUJOCO_SIM）。
- 21:45 **D-0012**: R-003 への回答（窓 φ 30.51〜48.49°、ダウエル、パッド）、**±4° の危険体積（Design の計算）+4° = 151、−4° = 覆いなし 319 / 覆いあり 23**（Engineering の補間 205 / 13 は過小）、覆い 3 案（A 8° の殻 / B 5° / C 丸い襟巻き）、ToF 小基板（肉球 S2）、フード昇降 3 案（推奨 L2 TPU 板ばね耳）、統合版 v2。
- 21:48 **User: 覆いは案 A**（D-0013）。R-011 完了。
- 21:58 **Engineering E-0012**: R-009 完了（機体側で範囲 [−4, +3] と窓外 40 °/s を強制。**既定オフ**、HT-001 の後に有効化）、HT-001 の対話ツール、覆いは取り込みを変えない（MUJOCO_SIM）、Design の ±4° を取り込み。
- 22:39 **D-0014**: 覆い A を襟と**一体**に、v2 の質量・重心。
- 22:46 **E-0013**: ファームのコンパイル成功（書き込みなし）、L2 の力の上限 2.8 N（E = 26 MPa で 1.17 N）、**フードの下がりきった 1 ビットを要求**、J1 サーボ箱の y の確認依頼。
- 22:56 **E-0014**: **Design の「TPU は E 3 MPa 級」は誤り**（7.2 mm² で底付き）→ P1（95A 級、3 mm）/ P2（E ≈ 10 MPa、4〜6 mm）、窓の端面の支圧 8〜12 MPa、**頭の重心 y の許容 |y| ≤ 4 mm（ダミー質量は不要）**。
- 23:04 **D-0015**: 訂正 2 件（E 3 MPa、ダミー質量）、既定 P1 + P2 の STL、範囲外の危険体積（+6° 1270 … +9° 1714、−7.5° 覆いあり 106。補間より 33〜74% 大）、**頭の質量は殻でも 137〜234 g（予算 90 g の 1.5〜2.6 倍）**、フードの端の 1 ビット = 磁石 + ホール素子（HT-013）、J1 サーボ箱の y = 35 mm。

### 2026-10-01 — 印刷のまとめ・この軌跡
- 02:21 **D-0016**: 印刷するものを `docs/design/print_all/` にまとめた（P0〜P3）。**ToF 基板の長さが文書 18 mm・CAD 16 mm で食い違っていた → 18 mm に直し、ポケットを上開きに**（閉じた箱では基板が入らない）。（`80e8be3`）
- 02:30 **この PRODUCT_HISTORY.md を作成**（User の依頼「軌跡を事細かに」「これからもそうして」）。

## 3. ブランチと担当（2026-10-01）

| ブランチ | 担当・中身 | 最新 |
|---|---|---|
| `main` | 基盤（EX-1 + Floor Watch フェーズ 1〜5、MQTT 修正）。`ai-shared/` は git 管理外 | `70601cd` |
| `agent/engineering-floor-watch` | 安全（トルク、挟み込み、フード昇降の枠組み） | `e30262e` |
| `agent/engineering-vision-sim` | H2 合成視覚・floorwatch の検出 | `8f5fd32` |
| `agent/engineering-scoop` | 取り込み機構（MuJoCo。B2 の比較スクリプト） | `285f014` |
| `agent/engineering-h1-j1` | H1 の J1・範囲の最適化・強制の配線・自律運用 | `5bfaabc` |
| `agent/design-floor-watch` | Design（CAD・試験片・報告。Fusion は別） | `80e8be3`（この節の時点）|
| `agent/floorwatch-farfield-roi` | 遠方 ROI | `7a5f536` |

Fusion: `Serpens_DESIGN_SD01_BEAN_KNUCKLE_RECOVERY_20260929`（元の CONCEPT は未変更。Recovery 複製に全部足している）。

## 4. User の判断の記録（誰が何を決めたか）

| 日 | 決定 | 内容 |
|---|---|---|
| 09-26 | PRODUCT.md | Floor Watch MVP = 5 サーボ。やらないこと（くわえて運ぶ・レーザー等）|
| 09-29 | USER-DEC-SERPENS-DESIGN-0001 | CSAR 採用 / 6 本目は暫定 Head Yaw / SD-01 継続（4 mm 一定は安全確定でない）/ Agent ごとに worktree / push は clean 確認後 / Fusion は Recovery copy / 背板は Recovery 後 / ENTRY-0011 は Engineering 回答待ち |
| 09-29 | USER-DEC-SERPENS-DESIGN-0002 | CSAR の撮影（CHILD_NEAR では写真確認を延期 等）|
| 09-29 | USER-DEC-SERPENS-0003 | 対象 3 歳未満・Safety Envelope 6 歳以下 / yaw 合計 145°（暫定）/ 機械式トルクリミッター / 継続実行 |
| 09-29 | USER-DEC-SERPENS-0004 | Head Yaw と 145°（145° = Body Curvature Budget。Head Yaw は独立した Safety Axis）|
| 09-30 | KNUCKLE DRUM 承認 | 報告の冒頭に「約 20 倍」を書き続ける / 試験片 / 背板は未解決のまま |
| 09-30 | 試験片 B の定義 | t = 口の下の板厚、c = 壁の下端のすき間（独立）。B2 → 訂正 |
| 09-30 | 「組み替えていい」「デフォルメ調でかわいく愛らしい感じ」| 頭 E3 統合版 |
| 09-30 | 覆い = 案 A | 襟の前縁を 8° 前へ延ばす薄い殻 |
| 09-30 | 自律運用 | User に聞くのは Design の見た目・形だけ |
| 10-01 | 「印刷するべきものまとめて」「軌跡を残して、これからも」| `print_all/`、この文書 |

## 5. 主要な設計・安全の決定（Engineering / Design、PROVISIONAL を含む）

- **安全は最下層**（ESP32 が単独で止まる。停止は StopSupervisor に集約。緊急停止はラッチ）。上限は機体側でも強制。
- **指の挟み込み: すき間は 5 mm 未満か 25 mm 以上**（09-29）。曲げた姿勢は形だけでは満たせず、KNUCKLE DRUM で約 90% 減らし、残りは覆い・トルク制限・範囲制限で。
- **yaw 合計 145°**（Body Curvature Budget）。眠りの三日月（180°）は不採用 → 「首をかしげる」[50, 45, 30, 20]。
- **取り込み**: 開放底フード + 漏斗 + ゲート。段差 t を 0 に（板なし）。c は床から 0〜1.0 mm。昇降は自重降下、上げる側 ≤ 2.8 N。
- **J1**: 範囲 [−4, +3]（θ_E、PROVISIONAL）、窓 −2〜+1°、ストッパー = 鋼ダウエル φ3 + TPU パッド、覆い A、強制は HT-001 の後。
- **ToF**: 用途は崖の 2 値（c・t の測定には使えない）。横スキッド前端。
- **Design の見た目**: Bean 頭（E3）、同心ナックル → KNUCKLE DRUM、口の前に床に触れる部品なし、かわいいデフォルメ（目・頬のピンク・丸い足）。

## 6. 数値の推移（変わった数を日付つきで）

| 量 | 推移（出典）|
|---|---|
| 曲げた姿勢のすき間（幅 5〜12.5・深さ 8 以上）| まっすぐ 124 mm³。曲げ: p1 6807（09-30 昼）→ KNUCKLE DRUM で 2558 → 背板の層 約 1020 が残る。**約 20 倍（18〜24 倍）**（CAD_CONCEPT）|
| 背板の層 J2〜J5 p1 | 1373 → (a) 52 / (b) 71 mm³（案。現行 CAD は未採用）|
| J1 範囲（θ_E）| −5〜+10°（09-30 昼の暫定）→ −5〜+3°（E-0009）→ **−4〜+3°**（E-0011）|
| J1 の危険体積（θ_E、mm³）| +3° 44 / +4° 151 / +5° 601 / +6° 1270 / +7° 1432 / +8° 1584 / +9° 1714 / +10° 1562。−4° 319（覆い A で 23）、−5° 401（29）、−7.5° 1350（106）。**符号と補間の訂正を経た値**（CAD_CONCEPT）|
| 口の前の禁止域の部品 | 15,290 → 0 mm³（配置案）|
| 照明の近/遠比 | 40/33 → 15/11（2 灯）→ 斜めを口の前の角へ 35 → 横スキッド前端 17.4 倍 |
| フード昇降のストローク | 10 / 8 / 5 → **4 mm**（すき間 ≤ 4）。上げる力 24〜60 N（SG90 停動）→ TPU 板ばね耳 約 1.2 N（prior）|
| TPU パッド | E 3 MPa 級 t 3〜6（誤り）→ **P1 95A 級 t 3 / P2 E≈10 MPa t 4〜6**（Engineering）|
| 頭の質量 | ASSUMED 93 g（SD-01 初期）→ robot.yaml 約 90 g → 概念の頭は殻にしても 137〜234 g（**予算超過**、CAD_CONCEPT）|
| あごの実体 | 166,295 mm³ → v1 109,844（−34%）→ v2 111,914（−32.7%）|
| トルク | 0.45 N·m 上限（C044 の資料値）、レジスタ比 0.287 → 0.167、J3〜J5 許容 約 0.25 N·m（OPEN）、J7 静的 0.204 N·m（訂正）。**5.7 N・0.25 N·m は暫定** |
| テスト | 463 passed（09-29 の CLAUDE.md）→ 563 passed / 1 skipped（vision-sim、09-29）|
| 頭のセンサー基板の LED 電流（NSSW157T 1 個、最小/公称/最大）| 3V3・20 Ω: 8.5 / 23.7 / 38.8 mA（Stage 1、Rds(on) 0.05 Ω 仮定）→ **8.5 / 23.6 / 38.8 mA**（Stage 2、Si2302CDS の最大 0.075 Ω）= 80 mA 時の光量の 11 / 30 / 49 %。5V・33 Ω 2010: 45 / 59 / 73 mA（74 %）。3V3 の外部負荷 最大 158 mA。**計算（SIMULATION / ASSUMED を含む）**、ENTRY-K-0001 |

## 7. 訂正・撤回の記録（間違えたことと直し方）

| 日 | 何が間違っていたか | 直し |
|---|---|---|
| 09-30 昼 | ボクセルの負の切片バグ（箱の外の区間が行を全部埋める）→ 「尾の刃」が誤検出 | `gap_check.py` を修正、Fusion の切断を戻した（D-0004）|
| 09-30 | 「脇の V は形で消せない／柔らかいカバー」 | **撤回**（KNUCKLE DRUM で約 90% 減、D-0004）|
| 09-30 | FLANK SKIRT のフラップ | すき間が増えた → 不採用（部分的な 3D モデルの限界）|
| 09-30 夕 | B2: 板を足の帯の下に敷き、c を板の上面から | シミュのコード（c は床から、板は空間の中だけ）と不一致 → 訂正（`CORRECTION_2026-09-30.md`）|
| 09-30 夜 | **J1 の符号（CAD は + が下げ）**。「負 = 頭を下げる」は誤り | 範囲の端は −5° 401 / +10° 1562（601/2062 は入れ替わり）（`j1_sign_correction`）|
| 09-30 夜 | J1 サーボ箱 y ±22.6（ASSUMED）| Fusion の REF は y ±18。再計算しても同じ（D-0011）。y = 35 mm（D-0015）|
| 09-30 夜 | Engineering の −4° = 205（補間）| Design の計算 **319**（覆いあり 13 → 23）（D-0012）|
| 09-30 夜 | 「TPU は E 3 MPa 級が要る」 | **撤回**。7.2 mm² では底付き。P1 / P2（D-0015）|
| 09-30 夜 | 「−y 側にダミー質量」 | **撤回**。許容 |y| ≤ 4 mm（D-0015）|
| 09-30 夜 | Engineering の「+6〜+9° の補間 728〜1290」| Design の計算 1270〜1714（33〜74% 大）（D-0015）|
| 10-01 | ToF 基板の長さ（文書 18、CAD 16）、ポケットが閉じていた | CAD を 18 に、ポケット 18.4、上開き（D-0016）|
| 09-30 | Engineering 回答を Design が「確定」と書いた（D-0007/D-0008）| 「Design の見積もり（Engineering 未検証）」に位置づけ直し |
| 09-30 | REQUESTS の行の壊れ（`\1` の制御文字）、番号の重複 | 直した（統合した）|
| 09-29 | ENTRY 番号の重複（0004 / 0005 / 0013 / 0023 …）| ENTRY-D-xxxx / ENTRY-E-xxxx の付け方へ（ENTRY-0022、D-0001、E-0001）|
| 09-30 | Engineering の「+3° で体積が 13.7 倍に跳ねる（膝）」 | Design の +4° = 151 mm³ で訂正。膝ではなく拘束で決める（E-0011 → E-0012）|
| 09-30 | Engineering: 床接触モデルの遅れの符号、ENC_MOTOR は負荷信号が要る、モンテカルロ表 | 符号修正、負荷信号を要件化、信頼できない表を削除（H1 `j1_floor_contact`）|
| 09-30 | Engineering: J7 の静的トルク 0.020 N·m | 0.204 N·m（robot.yaml の持ち上げ質量から）（E-0007）|
| 09-30 | Engineering: 「ファームのコンパイルは未確認」と書いた | arduino-cli で成功（ガード OFF/ON とも）。ENTRY / docs を訂正（E-0013）|
| 09-30 | 幅広 J7 のテストが強制オン化と競合 | `neck.floor_watch_enforce` False でピン留め（他の 1 件は全件通過）|
| 09-29 | 合成画像の採点が原因の誤検出を検出器の不具合と見た | 「回帰テストは修正なしで落ちることを確認する／まず合成の採点を疑う」を lessons に |

## 8. 成果物の地図（主なもの）

- 制御・安全・画像処理: `serpens/`、`config/robot.yaml`、`docs/product_status.md`、`docs/safety_limits.md`、`docs/verification_status.md`。
- Design 報告: `docs/design/`（`gap_check_report*.md`、`plate_layer_*`、`j1_pitch_*`、`j1_sign_correction_*`、`mouth_front_layout_*`、`stopper_v2_r003_*`、`j1_cover_variants_*`、`tof_board_placement_*`、`hood_lift_*`、`hood_endstop_sensing_*`、`head_e3_integrated_v2_notes_*`、`cad_reflection_*`）。
- 試験片・印刷: `docs/design/print_all/PRINT_LIST_ALL_2026-10-01.md`、`test_piece_b/B2/`、`knuckle_test/`、`j1_cover_v2/`、`j1_cover_adopted/`。
- 道具: `docs/design/tools/`（`gap_check.py`、`gap_radial.py`、`j1_cover_variants_eval.py`、`hood_lift_check.py`、Fusion 用スクリプト）。
- 共有: `ai-shared/`（`integration-log.md`、`design-state.md`、`engineering-state.md`、`REQUESTS.md`、`HARDWARE_TODO.md`、`AUTONOMY.md`、この文書）。
- 教訓: `ai-outbox/lessons/2026-09-29_LESSON-DESIGN-0001.md`（22 項目）。

## 9. 更新ログ（ここへ追記していく。新しいものを下に）

### 2026-10-01 02:30 — 軌跡の文書を作成（Design）
- 依頼（User）: 「今までのこのプロダクトの軌跡を事細かに描いたファイルを作って、そしてこれからもそうして」。
- やったこと: git ログ（全 178 コミット）・integration-log の全 ENTRY（約 60）・design-state・DECISIONS・PRODUCT.md から、このファイルを作成。§0 に更新ルール、§1 に現在地、§2 に日ごとの年表、§4 に User の判断、§6 に数値の推移、§7 に訂正・撤回の記録。
- 決めたこと: 以後、**ENTRY を書くたびに §9 へ 1 節を足し、§1・§6・§7 を最新に保つ**（Design が主に更新。Engineering も §9 に追記してよい）。AUTONOMY.md のループに 1 行足した。
- 出したファイル: `ai-shared/PRODUCT_HISTORY.md`（正本）、`docs/PRODUCT_HISTORY.md`（ブランチのコピー）。
- 待ち: 印刷・実機（HT-001 / 007 / 008 / 009 / 012 / 013）。

（ここから下に、新しい節を追記する）

### 2026-10-01 — Engineering 側の追記（軌跡の二重化の解消）
- 同じ User の依頼（「軌跡を事細かに」「これからもそうして」）を Engineering も受けていて、`agent/HISTORY.md` を作りかけていた。**年表が二重にならないよう、この文書を正本とする。** Engineering は git に入る自動台帳 `agent/HISTORY.md`（`python tools/update_history.py`。全コミット・ブランチの地図・DECISIONS の見出し・ENTRY の索引）だけを持ち、手書きはここへ足す。
- §7 に Engineering 側の訂正 6 件を追記（膝の主張、床接触モデル、J7 静的トルク、ファームのコンパイルの記述、幅広 J7 テストのピン留め、合成採点の教訓）。
- 別件: KiCad `snake-main-board`（`serpens/snake-main-board/`、入れ子の別 git。`origin` = `github.com/hattoir/snake-main-board`（private））。回路図は R1/R2 並列（0603）、基板は Edge.Cuts 20 × 12 mm・F.Cu 0.25 mm のトラック 2 本（pcbnew で作成。`.kicad_pcb` は手書きしない）。DRC（`--schematic-parity`）違反 0 / 未接続 0 / パリティ 0。コミット 156117b・50509da（User）、bfff9d7（Claude）。**push と BoardRepo MCP の認可は User 待ち**。BoardRepo 上の表示は未検証。
- 待ち: HT-001〜004 / 007〜013（実機・印刷）、R-013（HT-001 一致でガードを有効化）。

### 2026-10-01 01:00〜02:40 — 頭のセンサー基板 head-sensor-board（KiCad Agent）Stage 1・Stage 2
- **先頭の注意（変更なし。この節は電子系の試作基板の話）**: KNUCKLE DRUM 後も、まっすぐ比で約 20 倍のすき間が残る。5.7 N・0.25 N·m は暫定（SAFETY_UNVERIFIED）。安全・合格の語は使わない。
- 依頼（User、2 回）: ①「Floor Watch の頭のセンサー基板（試作用）を作る。`serpens\head-sensor-board` を新規リポジトリにし、GitHub に非公開 `hattoir/head-sensor-board` として push。**4 段階（仕様・部品表 → 回路図 + ERC → 外形・配置案 → 配線・DRC・ガーバー）で、各段階の終わりで止まって確認を待つ**」。②（Stage 1 の確認事項への回答）外形 40×25 mm・ToF はジャンパー線・6 mm 制限は LED だけ・ToF のピン配置は現物まで未確定・LED の電源を半田ジャンパーで 3V3/5V・3V3 総電流を Wi-Fi/カメラ込みで再計算・GPIO 割り当て承認・追加購入承認。
- Stage 1（commit 90ef2b9）: 仕様・部品表・GPIO 案・LED の電流計算（`docs/spec.md`、`tools/led_budget.py`）。**NSSW157T は 80 mA 級（VF 2.8〜3.4 V @80 mA）で、3.3 V では 8.5〜38.8 mA（公称 約 30 %）しか流せない**ことを原本（Nichia STS-DA1-1913）で確認。出典: Nichia・ST DS12385・Seeed wiki / 図面・Espressif。
- Stage 2（commit 85a61fe）: 回路図（KiCad 10、A3、40 部品）を生成。XIAO ESP32S3（2×7 ソケット）、VL53L1X ヘッダ ×2（ジャンパー線）、LED チャンネル ×2（NSSW157T + AO3400A、PWM、外付けヘッダ J3/J4、半田ジャンパー SJ で 3V3（20 Ω 0603）/ 5V（33 Ω 2010））、プルアップ（XSHUT 実装・I2C DNP）、TP ×8、デカップリング、M2 穴。**ERC 0 件（厳格版も 0 件）、ネットリスト 25/25 一致、全ピンがフットプリントのパッドに存在**。自作ライブラリ 5 点（`libs/`）。BOM（`docs/bom.md`）、BoardRepo 用 zip（User が手動アップロード）。
- 数値（出典）: LED 3V3 で 8.5 / 23.6 / 38.8 mA、5V で 45 / 59 / 73 mA（計算。VF(10 mA) はグラフの目視 = 参考値、Vcc は仮定）。3V3 の外部負荷 最大 158 mA。Webcam 撮影ピーク 366 mA（Seeed wiki）を足して 524 mA（700 mA の 75 %）。**Seeed のカメラ表 MAX ≒ 0.65 A（条件の記載なし = 未確認）なら 808 mA（115 %）**。5V 合計 493 mA（USB 2.0 の 500 mA 以内）。MOSFET: AO3400A VGS(th) 最大 1.45 V / RDS(on) < 48 mΩ @2.5 V、Si2302CDS 0.85 V / < 75 mΩ（原本）。ESP32-S3 Wi-Fi 送信ピーク 340 mA、GPIO IOH 40 / IOL 28 mA（DS v2.2）。
- 訂正・仮定の更新: LED 公称電流 23.7 → 23.6 mA（MOSFET の Rds(on) 仮定を 0.05 → 0.075 Ω）。5V 側の抵抗は最初 24 Ω/2010 を考えたが、USB 2.0 の 500 mA に収まらない（5V 合計 536 mA）ので **33 Ω/2010** にした。Stage 1 の「5V ピンは接続しない」は、User の「5V も選べる」に合わせて「半田ジャンパーの 5V パッドにだけつながる（既定は開放）」と解釈した（User に報告）。自分のミス 2 件を直した: `justify center`（KiCad に無い値）で回路図が読めなかった、シンボルライブラリの形式番号を回路図と同じ 20260306 にして読めなかった（標準は 20251024）。
- 決めたこと（誰が）: User: 外形 40×25 mm（変数）、ToF はジャンパー線、6 mm は LED のみ、GPIO 割り当て、追加購入。KiCad Agent: R_LED 20 Ω（3V3）/ 33 Ω 2010（5V）、MOSFET 候補 AO3400A / Si2302CDS、ゲート 220 Ω + 100 kΩ、電流検出 1 Ω。
- 出したファイル: `serpens/head-sensor-board/`（別 git。`docs/spec.md`・`bom.md`・`erc_report*.txt`・回路図 PDF、`libs/`、`tools/`）、ENTRY-K-0001、REQUESTS R-020。`serpens/.git/info/exclude` に `head-sensor-board/` を追加（親で追跡しない）。
- 待ち: User: Stage 2 の確認、BoardRepo のアップロード（`C:\2026\Serpens_Home AI\head-sensor-board_upload.zip`）、ToF 小基板の現物のピン配置。Engineering: ENTRY-K-0001 の (a)〜(c)。Stage 3（外形・配置案）は User の確認後。

### 2026-10-01 02:45〜03:15 — 頭のセンサー基板 head-sensor-board Stage 3（KiCad Agent）
- **先頭の注意（変更なし。この節は電子系の試作基板の話）**: KNUCKLE DRUM 後も、まっすぐ比で約 20 倍のすき間が残る。5.7 N・0.25 N·m は暫定（SAFETY_UNVERIFIED）。安全・合格の語は使わない。
- 依頼（User）: Stage 2（回路図・BOM）を確認済み。5V ピンは「SJ の 5V 側パッドだけ・既定は開放」の解釈でよい。ToF のピン配置は現物まで未確定（ガーバーは出さない）。BoardRepo は User が zip を上げる。**Stage 3 = 外形 40×25 mm（角 R1・M2 穴 2・変数）と部品配置案（配線なし）**。LED と J3/J4 は縁、ToF ヘッダは引き出しやすい縁、USB-C は外向き、TP は測定しやすい側。**注意 2 点（5V は試験用・493 mA は 500 mA ぎりぎり / 3V3 は Wi-Fi・撮影・LED 100 %・ToF ピークを同時にしない）を README と回路図の注記に残す**。
- やったこと（commit 756b482）: `tools/gen_pcb.py`（KiCad 同梱の Python）で基板を生成。外形・穴を変数化、フットプリントを回路図のネットリストから読み込み（ネット・フィールド・回路図とのリンク）、配置図 PNG（`docs/placement_annotated.png`、KiCad の上面・裏面の描画）。配置: USB-C 左 / LED と J3・J4 右寄りの縁 / ToF ヘッダ 上下の長辺 / TP は上面（ILED と GND を 1 か所）/ XIAO の下に高さ 0.9 mm 以下の 0603・2010 / 裏面は部品なし。**DRC（回路図との対応つき）は未配線 64 以外 0 件。40×25 が下限（39.5×25・40×24.8 で重なる）= 余裕ゼロ**。自作ライブラリに TP（輪なし）を追加、XIAO のコートヤードをピン列の帯だけに変更。
- 数値（出典）: 面積は DRC のコートヤード重なりで確認（計算）。LED の高さ 0.52 mm（Nichia データシート ✅）。XIAO の下の部品の高さ制限 0.9 mm とソケット 8.5 mm は仮定（🔴）。
- 訂正・自分のミス: 最初の配置は M2 穴の禁止範囲と ToF ヘッダが重なり、TP の銀色の輪が名前の刻印と重なった → 穴を右の 2 角へ、TP を輪なしに。`pcbnew.FootprintLoad` が `board.Remove()` のあとで壊れる（SWIG）ので、空の雛形から作り直す方式にした。スクリプトに `\n` を含む文字列をシェルから流し込むと改行に化けて壊れることが 3 回あった（以後、ファイル編集ツールで書く）。
- 決めたこと（誰が）: User: 配置の方針（縁の使い方）、運用上の注意。KiCad Agent: 下半分 = L チャンネル（XIAO の D0〜D6 の列に近い側）、TP2（GND）を ILED の TP の隣に置く、M2 穴の位置。
- 出したファイル: `serpens/head-sensor-board/`（`docs/placement_*.png`・`drc_report.txt`・`spec.md` §6・§7、`tools/gen_pcb.py` ほか）、ENTRY-K-0002、`C:\2026\Serpens_Home AI\head-sensor-board_upload.zip`（基板は配置つき・配線なし）。
- 待ち: User: Stage 3 の確認、zip のアップロード結果、ToF 小基板のピン配置。Engineering: ENTRY-K-0001・K-0002。Stage 4（配線・DRC・ガーバー）は User の確認後、ガーバーは ToF のピン配置の確認後。

### 2026-10-01 02:55 — KNUCKLE 試験片を User が印刷（Design が確認手順を作成）
- 依頼（User）: `docs/design/knuckle_test` のものを印刷した（P3 の任意枠を先に印刷）。
- やったこと: 確認手順 `knuckle_test/KNUCKLE_TEST_PROCEDURE.md` と記録表 `KNUCKLE_TEST_LOG_template.csv`（R46 / R34 × 角度 0・±25・±50° × 上中下 = 30 行）、HARDWARE_TODO に **HT-014** を追記。何がわかるか: 円柱と椀のすき間が実物でも約 4 mm のままか、5〜12 mm の帯が無いか、端 ±52° の止まり、見た目（User の判断）。**約 20 倍のうち背板の層は確かめられない**ことも明記。
- 決まったこと: P3 を先に印刷したので、P0（B2）は未印刷のまま。B2 の優先は変えない。
- 待ち: User の実測（HT-014）、B2 の印刷（P0）。

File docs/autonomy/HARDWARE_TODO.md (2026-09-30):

# HARDWARE_TODO — 実機でしか確かめられない項目（User が測る）

AI は**自分で決めず**、ここに「何を・どう測るか・使う道具」を書く。User が測ったら、該当項目の「結果」欄に値を貼る（または指定のファイルに置く）。
AI は次の周で取り込み、prior を置き換える（`AUTONOMY.md` §6）。**購入は User の承認が要る**（AI は買わない）。
**5.7 N・0.25 N·m は暫定（SAFETY_UNVERIFIED）。ここで測った値も、User がしきい値を決めるまで「安全の合格」とは書かない。**

形式: `HT-xxx` / 優先度 / 何を測るか / 手順 / 道具 / 記録先 / 測ったあと AI がやること / 結果

---

## HT-001（P0）J1-0: 実機の符号の確認 — **ストッパーの窓を切る前に必須**

- **何を**: J1（Engineering の J7）に **+5°** を指令して、**頭が上がるか**（+ = 頭を上げる が実機で成り立つか）を目視と前縁の高さで確かめる。
- **なぜ**: Engineering は + = 頭を上げる（`robot.yaml`・MuJoCo・口の前縁 +0.95 mm/°）。Design の CAD の姿勢変換は + = 下げ。実機のサーボの取付向き・ホーンでの確認は未実施。**窓・ピンの角（φ 30.5〜48.5° 等）は、この確認の後に切る**（ENTRY-E-0009 / E-0012）。
- **手順**（対話ツール **`tools/j1_sign_check.py`** がやる。先にモックで練習できる: `python tools/j1_sign_check.py`）:
  1. **通電の前**: `python tools/servo_setup.py` の 3（入力電圧の設定）→ 2（スキャン）で、J7 が応答することと最高入力電圧（14 番地）を確認（H1 README §0）。電源は安定化電源 7.4V・電流制限 3A から（12V は入れない）。**手元に電源断スイッチ。指を入れない。**
  2. 頭の模型（実機の頭でもよい。質量 約 93 g + フード 11 g）を J7 に付け、頭が床・机に当たらない高さで支える。
  3. `python tools/j1_sign_check.py --bus feetech --port COM5`（既定: 角度 +5°、速さ 20 °/s、トルク比 0.5 = 安全上限に対する割合）。YES を入力 → 0° へ → 前縁の高さを読む（ダイヤルゲージまたは定規）→ +5° → もう一度読む → 「上がった (u) / 下がった (d) / 動かない (n)」を入力 → 0° へ戻る → トルク OFF。
  4. **動かなかった（n）場合**: `--torque 1.0`（= 安全上限。それ以上は書かない）で 1 回だけ。それでも動かなければ、取り付け・配線・電源を確認し、HT-004 の「動き出しの最小の上限」の測定へ（**上限 ≤ 0.034 N·m ではバックドライブ（prior 0.05〜0.5 N·m）より小さく動けない可能性**がある。E-0009）。
  5. **符号が逆（d）だった場合**: **`config/robot.yaml` を自分で変えない**。結果をこのファイルの「結果」欄に書き、Engineering が `direction` の扱いを決める（DECISIONS に書く）。
- **道具**: ST3215-C044（未購入）、サーボの USB 接続ドライバ（Waveshare Bus Servo Adapter 等。未購入）、安定化電源（7.4V・3A 制限）、電源断スイッチ、頭の模型、ダイヤルゲージ 0.01 mm（または定規。+5° で前縁が約 4.7 mm 動く）。
- **記録先**: `hardware/prototypes/H1_joint/j1_sign_check_YYYYMMDD.csv`（**ツールが自動で 1 行書く**。列: date, time, operator, servo_id, test_id, torque_ratio, commanded_deg, present_deg_before/after, head_moved, front_edge_height_before/after_mm, sign_matches_engineering, note）。
- **合否**: `sign_matches_engineering = True`（+5° で head_moved = up）。**その個体・その取り付けの向きに限る HARDWARE_VERIFIED**。取り付けの向きを変えたら測り直す。
- **AI が次にやること**: 一致 → Design の窓を θ_E で確定（`REQUESTS` R-003 の「HT-001 の後に切る」を解除）。逆 → DECISIONS に `direction` の扱いを書き、Design に θ の読み替えを依頼。動かない → HT-004 の τ_move を最優先に。
- **結果**: （未実施）

## HT-002（P0）J1 の押す力の測定（ロードセル + HX711）

- **何を**: J1 の横スキッド前端（腕 44.2 mm）が床（荷重計）を押す力。トルク制限レジスタ（48 番地）= 8 / 12 / 20 / 167（1000 = ストールの 100%）で。**サーボ OFF（重力だけ）の荷重も測り、差をサーボ分とする。** 予想: 8/1000 で 0.15〜0.76 N（HG-H1 の prior、実効上限 0.0067〜0.0336 N·m ÷ 0.0442 m）。
- **なぜ**: 「上限 0.022 N·m で頭の重さ（約 1 N）以下に抑えられるか」「動き出しの最小の上限 τ_move」の実測（J1-3 / J1-4）。prior の実効上限の誤差 e ±40% を置き換える。
- **手順**:
  1. **ロードセル**: 定格 500 g〜1 kg（≈ 5〜10 N）、ひずみゲージ式のビーム型（またはボタン型）。**予想 0.15〜0.76 N は定格の 3〜15%** なので、500 g が望ましい。HX711（ゲイン 128、80 SPS）で読む。校正は既知のおもり（20 / 50 / 100 / 200 g）で 4 点（傾きと直線性。`force_n = (raw − tare) × N/count`）。
  2. ロードセルを、床面の高さに固定（剛い台。たわみ 0.1 mm 以下）。頭の模型の横スキッド前端が荷重面の中心に載るように置く（J1 軸から 44.2 mm。**測る力は、腕 44.2 mm の先の鉛直成分**）。
  3. 各条件の前に**風袋（tare）**を取る（頭を持ち上げた状態）。条件: 48 番地 = 8 → 12 → 20 → 167（**小さい方から**）、位置指令 = 床より 10 ステップ下（約 0.9°）。各条件で 10 秒（80 SPS）記録して平均・標準偏差。
  4. 同じ位置で **トルク OFF（重力だけ）**の荷重を測る（頭の重さの分担）。
  5. 各条件 5 回（毎回、頭を持ち上げてから下ろす）。温度・電圧・現在負荷（60 番地）・現在電流（69 番地）も記録。
- **道具**: ロードセル（500 g〜1 kg）+ HX711 基板、読み出し用の MCU（ESP32 / Arduino）または PC、既知のおもり、頭の模型、ST3215-C044、安定化電源、電源断スイッチ。**購入リスト**（下）を参照。
- **記録先**: `hardware/prototypes/H1_joint/j1_push_force_YYYYMMDD.csv`（雛形 `j1_push_force_template.csv`。列: date, operator, test_id, register_torque_limit, torque_on, goal_below_floor_steps, force_n_mean, force_n_sd, n_samples, load_reg, current_a, temp_c, voltage_v, note）。
- **合否（提案）**: サーボ分の力 ≤ 頭の重さ（約 1 N）かつ 2.8 N 以下（**5.7 N は暫定。安全の合否は User がしきい値を決めるまで出さない**）。
- **AI が次にやること**: e（実効上限の誤差）を `assumptions.yaml` に足して `j1_head_pitch_check.py` と `j1_range_opt_report.py` を回し直す。押す力が 0 に近ければ「上限 0.02 では動けない」側として τ_move の測定（J1-4）へ。
- **結果**: （未実施）

## HT-003（P0）衝撃ピークの測定（ADS1256）

- **何を**: J1 がストッパー（窓の端）に当たったときの**衝撃のピーク力**。速さ 60 / 90 / 120 °/s（**ファームの `LIMIT_HEAD_SPEED_DPS` = 120 °/s が上限**。180 °/s はベンチのサーボを直接駆動する場合だけ。機体の経路では出ない）、緩衝（なし / TPU パッド E 10 MPa・厚さ 4〜6 mm）、端の手前の減速の有無で。**同じ装置で、フード昇降の落下のピーク（10 / 20 mm/s）も測る**（`flank_v.md` §F）。
- **なぜ**: 衝撃は**トルク上限では抑えられない**（HG-H1）。Engineering の見積もり（ω√(J k)。鋼 + 減速なし 120°/s で 12〜63 N（パッドの有無による））は prior。J（反射慣性）と k（剛性）が UNKNOWN。ピンの強度・安全率（`j1_range_opt_2026-09-30.md` §4）の根拠になる。
- **手順**:
  1. **ロードセル**: 5〜10 kg 級（固有振動数が高い小型の圧縮型）+ **ADS1256**（PGA 64、10〜30 kSPS、単一チャンネル）。**ロードセルの固有振動数を、軽いハンマーの打撃で確認**（ピークが装置の共振で歪む。カットオフはサンプリングの 1/5 以下）。校正は静的な既知のおもり（0.5 / 1 / 2 kg）。
  2. 窓の端を模した当たり面（PLA 板、次に TPU パッドを貼ったもの）をロードセルに固定し、J1 の動きの端に置く（ピンの位置 = 腕 36〜48.5 mm）。
  3. **トルク上限 8/1000（0.022 N·m）の状態から始める**。J1 を指定の速さで当てる。**167 は最後**（上限が効いているかも同時に確認）。各条件 5 回。10 kSPS で、当たる前 100 ms から後 200 ms を記録（トリガー）。
  4. ピーク力・立ち上がり時間（10〜90%）・減衰を記録。
  5. **J・k の当てはめ**: `F_peak = ω √(J k)`。同じ k（当たり面）で ω を変えて F_peak が ω に比例することを確認 → 傾きから √(J k)、k は立ち上がりの力の傾き（力 ÷ 押しつぶし）から。
- **道具**: ロードセル（5〜10 kg 級）、ADS1256 基板、SPI で読める MCU（ESP32 など）または PC、当たり面（PLA / TPU 各種）、頭の模型、ST3215-C044、電源断スイッチ、ハンマー（共振の確認）。購入リストを参照。
- **記録先**: `hardware/prototypes/H1_joint/j1_stopper_impact_YYYYMMDD.csv`（雛形 `j1_stopper_impact_template.csv`。列: date, speed_dps, damper, decel_deg, torque_limit_reg, peak_n, rise_ms, decay_ms, sample_rate_hz, load_cell_fn_hz, note）。
- **AI が次にやること**: J・k を `assumptions.yaml` に入れ、ストッパーの安全率（鋼ダウエル φ3 の曲げ）と最適化を更新。PLA ピンが足りるか、TPU パッドの効果を実測ベースで再判定。
- **結果**: （未実施）

---

## HT-004（P1）J1 の不感帯・バックラッシ・動き出しの最小の上限・較正の繰り返し精度（J1-1 / J1-2 / J1-4 / J1-5 / J1-6）

手順・記録・判定は `hardware/prototypes/H1_joint/j1_head_pitch.md`（§1 の表と §2 の判定表）。**これが決まらないと、範囲を +2° / −3° に狭められるか、取り込みの帯 [−1.0°, +1.15°] を保てるかが決まらない**（`j1_range_opt_2026-09-30.md` §5b: D + B が 6 ステップ以下なら +2°、11 ステップ（1°）を超えると帯を外れる）。
- **道具**: ダイヤルゲージ 0.01 mm（前縁の高さ。1 ステップ = 0.083 mm）、出力軸に付ける指針または角度盤（バックラッシ = 出力側の実測）、ばね秤またはロードセル（J1-4 の力）、サーボの現在位置（56 番地）・現在負荷（60 番地）・現在電流（69 番地）を 10 Hz 以上で記録する PC。
- **記録先**: `hardware/prototypes/H1_joint/j1_head_pitch_template.csv`（J1-1〜J1-6 の test_id 別）。
- **AI が次にやること**: D・B を `assumptions.yaml` に入れて `j1_range_opt_report.py` → 範囲（+2° / +3° / +4°、−3° / −4° / −5°）を再判定。**結果**: （未実施）

## HT-005（P1）ToF の崖判定（T6-1〜T6-4）と斜め LED の遮り（T4）

手順は `simulation/hardware_gaps/HG-H2_sensor_head/hardware_test_plan.md`。道具: VL53L1X（小基板。Design の HT-011 の寸法）、高さ 6 / 9 mm の台、床 4 種、机の縁・段差 60 mm、5〜80 mm/s で動かす台。**結果**: （未実施）

## HT-006（P2）フード昇降の縁の接触面積（感圧紙）と落下ピーク

手順は `simulation/hardware_gaps/HG-S3_torque_limiter/flank_v.md` §F。落下ピークは HT-003 の装置で。縁の接触面積は感圧紙（圧力測定フィルム）で。**結果**: （未実施。昇降機構の力の制限は Design の HT-008 の板ばね耳）

## HT-007（P1）B2 の観察（User が印刷中）

試験片 B2（`docs/design/test_piece_b/B2/`）。**記録は `ai-shared/B2_test_log_template.csv`（Design の v2 の列 + 実測厚さ・すき間・やすり掛け・押す速さ・位置ずれ）に書き、`ai-shared/b2_results/B2_test_log_YYYYMMDD.csv` として置く**（動画は別の場所でよい）。AI が `python tools/b2_compare.py <csv>`（ブランチ `agent/engineering-scoop`）で、シミュレーションとの比較 `simulation/results/b2_vs_sim.md` を作る。**シミュレーションの予測**: 垂直の板 t ≥ 0.002 mm は 0%（面取りなし）、t = 0 なら c 0〜1 mm で差なし、物の中心のずれ ≤ 5 mm。**観察の記録の要点**: 「入る」は入って残った、「戻る」は入ったが押す向きを止める・戻すと出た、「押されて逃げた」は口の前で押された。**結果**: （印刷待ち）

---

## 購入リストとの対応（**未購入。購入は User の承認が要る。Engineering は買わない**）

| 品目（候補の仕様） | 数 | 使う HT | 備考 |
|---|---|---|---|
| ST3215-C044（7.4V、1:191） | 1（H1 用） | HT-001〜004 | 電源・ヒューズ・トルク上限の実測（H1）と共通。**最優先** |
| サーボの USB 接続ドライバ（Waveshare Bus Servo Adapter 等）と USB ケーブル | 1 | HT-001〜004 | `tools/servo_setup.py`・`j1_sign_check.py` |
| 電流制限つき安定化電源（7.4V、3A）または INA226 つき 2S 電源 | 1 | HT-001〜004 | OQ-0104。12V は入れない |
| **ロードセル 500 g〜1 kg + HX711 基板** | 1 セット | **HT-002** | 静的な力（10 / 80 SPS）。校正用のおもり（20〜200 g）も |
| **ロードセル 5〜10 kg（小型の圧縮型）+ ADS1256 基板** | 1 セット | **HT-003**、HT-006 | 動的なピーク（10〜30 kSPS）。ESP32 か PC で SPI 読み出し |
| ダイヤルゲージ 0.01 mm（スタンドつき） | 1 | HT-001、HT-004 | 前縁の高さ・バックラッシ。すでにあれば不要 |
| 小型 VL53L1X 基板（Design の HT-011: 幅 12 mm 前後） | 2（左右）+ 予備 1 | HT-005 | 横スキッドの前端に入る寸法かは HT-011 で確認 |
| 鋼のダウエルピン φ3（長さ 10.5）+ リーマ φ3 | 10 本 | Design の HT-009 | 圧入・支圧の試験 |
| TPU フィラメント（E 10 MPa 級 = Shore 80A 前後、E 3 MPa 級 = 60A 前後、95A の 3 種） | 各 1 巻 | Design の HT-008、HT-003 のパッド | 硬さ（Shore）は計器があれば測る。無ければ板ばね耳のたわみから E を逆算 |
| すきまゲージ（0.02〜0.1 mm）、PET シート 0.05 / 0.1 / 0.2 mm | 1 | HT-007 | B2 の板・実測厚さ |
| 圧力測定フィルム（超低圧用） | 1 | HT-006 | 縁の接触面積 |

**最初に要るもの**: 1 行目〜3 行目（サーボ + ドライバ + 電源）で HT-001 / HT-004 が始まる。ロードセル 2 種は HT-002 / HT-003。**購入のときは仕様を Engineering に確認**（サンプリング・定格・SPI のピン）。

---

## （Design 追記 2026-09-30）HT-008（P1）フード昇降: TPU 板ばね耳の力・クリープと、パッドの硬さ

- **何を**: (a) 昇降の板ばね耳（TPU、幅 12 × 厚さ 1.4 × 長さ 9 の設計値）を、先端 4 mm 押したときの**力**（設計値の予想 1.2 N。E = 26 MPa の prior。0.8〜1.5 N）。(b) ストッパーのパッド用 TPU の**硬さ**（Shore）と、3 mm 厚のパッドを 20 N で押したときの**たわみ**（Engineering の k = 5 N/mm 級の仮定が成り立つか）。(c) 板ばね耳を 4 mm たわませたまま 1 時間置いた**戻り**（クリープ）。
- **なぜ**: フード昇降の上げる側の力は ≤ 2.8 N（Engineering の枠組み PROVISIONAL）。**E は prior** で、実測なしに「力が制限できた」とは書けない。パッドは E 3 MPa 級（柔らかい TPU）の仮定で、95A（E ≈ 26 MPa）では衝撃が減らない（E-0011）。
- **手順**: (1) 板ばね耳の試験片を印刷（TPU 95A と、あれば柔らかい TPU の 2 種）。(2) 片持ちで固定し、先端を**デジタルはかり（0.01 g 分解能、または 0.1 N 級のプッシュプルゲージ）**で押して、たわみ 1・2・3・4 mm の力を読む（定規かダイヤルゲージでたわみ）。各 5 回。(3) パッドの試験片（3 × 3.6 × 2）を万力の代わりにはかりの上で押し、力 5・10・20 N でのつぶれを読む。(4) 耳を 4 mm たわませて 1 時間置き、戻りを読む。
- **道具**: 3D プリンタ（TPU）、デジタルはかり（または プッシュプルゲージ）、ダイヤルゲージ（または ノギス）、ショア硬度計（あれば。無ければ材料のデータシートの値を記録）。
- **記録先**: `hardware/prototypes/hood_lift/tpu_leaf_YYYYMMDD.csv`（列: sample, material, b, t, L, deflection_mm, force_n, note）。
- **AI が次にやること**: E を逆算して `hood_lift_options` の力の表を更新。力が 2.8 N を超えたら板ばね耳を細く/薄く/長く直す（Design）、または案 L1 / L3 へ。
- **結果**: （未実施）

## （Design 追記）HT-009（P1）鋼ダウエルの圧入と窓の端面の支圧

- **何を**: (a) 鋼ダウエル φ3（長さ 10.5）を、印刷した首の芯の見本（PLA、穴 φ3.0、深さ 7）に圧入して、**引き抜きの力**（N）。(b) フードの窓の端面（PLA 2 mm の壁 + TPU パッド 3 mm）を、ダウエルで押して**壊れる／永久変形する力**（N）。
- **なぜ**: ストッパーの荷重は Engineering の prior（静的 10 N 級、衝撃 20〜30 N 級）。**窓の端面の支圧と、ダウエルの固定は未検査**。
- **手順**: (1) 見本 2 種（穴の径 φ2.95 / φ3.0 / φ3.05 を試す）を印刷。**穴はリーマで仕上げる**。(2) ダウエルを圧入・接着（瞬間接着剤）、はかりで引き抜く。(3) 窓の見本（フードの壁の切れ端）にパッドを貼り、ダウエルで**ゆっくり**押して、20 N まで荷重を読む（ばね秤またはロードセル）。**指を入れない。20 N を超えたら止める**。
- **道具**: 鋼の丸棒 φ3（ダウエルピン、購入は User の承認）、リーマ φ3、瞬間接着剤、ばね秤（0〜30 N）またはロードセル、印刷した見本。
- **記録先**: `hardware/prototypes/H1_joint/stopper_v2_YYYYMMDD.csv`（列: hole_dia, fit, pullout_n, window_load_n, deformation, note）。
- **AI が次にやること**: 穴の径・パッド厚を決める。支圧が足りなければ窓の端に金属のスリーブを足す案（Design）。
- **結果**: （未実施）

## （Design 追記）HT-010（P2）覆い（襟の前の殻）の実物のはめあい

- **何を**: 案 A / B / C の覆いを印刷し、首の襟の模型に付けて、J1 の**ピッチ ±4°**（手で回す）で頭・フードと**擦れない**（隙間 1.5 mm）こと。0.1 mm のコピー用紙・すきまゲージで測る。
- **なぜ**: ボクセルの計算（0.5 mm）は、覆いと頭の重なり 0 mm³ だが、**印刷の反り・襟の公差**は入っていない。
- **手順**: 覆い + 襟（Fusion の `NECK-V` の襟を切り出して印刷）+ 頭を仮に組み、手で ±4° 回す。擦れる場所を鉛筆で記録。**J1 の電源は入れない（手で回す）**。
- **道具**: 3D プリンタ、すきまゲージ、鉛筆。**記録先**: `docs/design/j1_cover_v2/fit_YYYYMMDD.md`。
- **AI が次にやること**: 隙間を調整（Design）。**結果**: （未実施）

## （Design 追記）HT-011（P2）ToF 小基板の実寸と窓の見通し

- **何を**: 購入する VL53L1X 小基板の**実寸**（幅・長さ・高さ・センサー窓の位置）を測り、`tof_board_placement_2026-09-30.md` の仮定（幅 12・高さ 3.2・長さ 18 [ASSUMED]）と比べる。実物を「肉球」（案 S2）の穴に仮置きして、センサー窓が下向きに見通せるか。
- **道具**: ノギス、購入した基板（購入は User の承認）。**記録先**: 同文書の表。**AI が次にやること**: 穴とスキッドの寸法を直す（Design）。**結果**: （未実施）

## HT-012（P2）マットのスキッドの押し込み剛性 k（頭の重心 y の許容の根拠）

- **何を**: 横スキッド前端（丸い先端 R6）を床（フローリング・マット）に 0〜1 N で押したときの**押し込み量**（mm）から k [N/mm] を求める。
- **なぜ**: 頭の重心の左右の偏り（Design の v2 で +2.8 mm）の許容が、左右のたわみの差 ≤ 0.05 mm（c₀ = 0.1 mm の半分）で決まり、**許容 y = 4.2 mm × k**（`j1_head_pitch_check.py`。k = 1 N/mm は仮定）。
- **手順**: HT-002 のロードセル（500 g〜1 kg）+ HX711 に床材（マット 1 枚 / フローリング）を載せ、スキッドの試験片（TPU または PLA、R6、先端の実物と同じ材質）を上から 0.1 N 刻みで 1 N まで押し、ダイヤルゲージ（0.01 mm）で押し込み量を読む。各 3 回。
- **道具**: HT-002 の装置、ダイヤルゲージ、スキッドの試験片、床材（マット・フローリング。絨毯は未対応）。
- **記録先**: `hardware/prototypes/H1_joint/skid_indentation_YYYYMMDD.csv`（列: floor, skid_material, force_n, indentation_mm, note）。
- **AI が次にやること**: k を `head_cog_y_limit_mm` に入れて許容を更新。k < 1 N/mm なら、重心 y の許容が 4 mm を下回るので Design に伝える。
- **結果**: （未実施）

## （Design 追記）HT-013（P2）フードの端の検出（磁石 + ホール素子）

- **何を**: 磁石（φ3 × 1.5）とホール素子（デジタル出力、SOT-23 級）の**検出距離・ヒステリシス**、磁石の向き（極性）、SG90 を動かしながらの**誤動作の有無**、実物の素子・基板の寸法。
- **なぜ**: フード昇降は SG90（電流・位置を返さない）なので、「下がりきった / 上がりきった」の 1 ビットが機構側に要る（E-0013 (4)）。Design の案 H（`hood_endstop_sensing_2026-09-30.md`）は寸法・素子が ASSUMED。
- **手順**: (1) 素子を基板に付け、磁石を 0.5〜3 mm の隙間で近づけて、ON / OFF になる距離を 0.1 mm 刻みで記録（往復で 5 回。ヒステリシス）。(2) 下 / 上の素子を 4 mm 離して、磁石を 4 mm 動かしたときに片方だけが ON になるか。(3) SG90 を動かしながら（電源共通・別電源の両方）、誤検出が出るか 100 回。(4) 磁石の向きを反転して同じ。
- **道具**: 磁石 φ3 × 1.5、ホール素子（DRV5032 / A1104 級。購入は User の承認）、ブレッドボード、MCU（ESP32 等）、ノギス、SG90。
- **記録先**: `hardware/prototypes/hood_lift/hall_endstop_YYYYMMDD.csv`。**AI が次にやること**: 隙間・素子の位置を確定（Design）、Engineering: 0.6 s のタイムアウトの実装の確認。**結果**: （未実施）

## （Design 追記）HT-014（P1）KNUCKLE 試験片の確認（User が印刷済み 2026-10-01）

- **何を**: R46 / R34 の玉・椀・板を組み、0 / ±25 / ±50° で、探針 d5 / d12 の入り方、円柱と椀のすき間（設計 約 4 mm）、端（約 ±52°）での止まり方、見た目を記録する。
- **なぜ**: KNUCKLE DRUM（User 承認）の実物確認。胴の層のすき間 約 90% 減（CAD_CONCEPT）が、印刷の公差・反りで崩れないか。**背板の層（約 20 倍の大部分）は確かめられない**。
- **手順・道具・記録**: `docs/design/knuckle_test/KNUCKLE_TEST_PROCEDURE.md`、`KNUCKLE_TEST_LOG_template.csv`。道具: 探針（`GAUGE_5mm_12mm`）、すきまゲージ / ノギス、コピー用紙、スマホ。
- **AI が次にやること**: 実測と CAD の差を形の余裕へ（Design）、5〜12 mm の帯があれば Engineering が接触半径の前提を見直す。**結果**: （未実施）

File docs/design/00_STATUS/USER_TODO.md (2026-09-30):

# User にやってほしいこと（優先順）

> 先頭の注意: KNUCKLE DRUM 後も、まっすぐ比で約 20 倍（18〜24 倍）のすき間の体積が残る。背板は未解決、J1 ピッチは回答待ち。

## A. 印刷して確かめる（Design は印刷・購入をしていない）

1. **円柱肩の試験片 R46 を印刷**（A1、PLA、インフィル 15 %、支え不要。約 270 g）: `docs/design/knuckle_test/print/KNUCKLE_R46_*.stl` ＋ `GAUGE_5mm_12mm_PLA.stl`
   - 板に椀 B を差し、玉 A を軸に載せ、0・±25・±50° で **探針 d5・d12 が入るすき間が無いか**、見た目・触感を見る
   - 見てほしいこと: 関節の玉の脇が円柱の肩として **5〜10 mm 張り出す外観**（「膝」）でよいか
2. **R34（J2）も印刷**（約 233 g）。**椀 B の STL に開いた辺 18 か所**。スライサの「修復」を通す
3. **試験片 B を印刷**（`docs/design/test_piece_b/print/`）: フード・リップ・スペーサー・クランプ棒は PLA、**スカートは TPU（A1 は外付けスプール、AMS を通さない、低速）**。手順・質量・試す物（1 円玉、CR2032、ビーズ、立方体）は README
4. 結果（写真・気づき）を Design に返す → KNUCKLE DRUM・試験片 B の形を直す

## B. 判断してほしいこと

| 判断 | 選択肢・補足 |
|---|---|
| 試験片 B の **前縁の「段差 0/0.3/1 mm」の解釈** | Design は「リップ板の下面が床から浮く高さ」と解釈した（スペーサー厚 1.0 → 段差 0、0.7 → 0.3、なし → 1.0）。違うなら教えてほしい。**試験片 B の元のブリーフがこの会話に無い**ので、A の続きと読んだ |
| KNUCKLE DRUM の **外観**（関節に膝） | 承認済み。実物を見て、続けるか調整するか |
| **物を拾う・回収する機構を第二段階に入れるか**（OPEN-012） | `PRODUCT.md` は「やらないこと」。A 研究のみ（現状）/ B 第二段階として頭に統合（PRODUCT.md の更新が先）/ C 見送り |
| 6 本目のモーター（Head Yaw か胴 yaw か） | H0（摩擦比の実測）の結果しだい（User Decision のまま） |

## C. 実機まわり（Design はしない）

- **H0（腹面の摩擦比 r の実測）は最優先のハード試験**のまま。結果が推進方式・6 本目・腹面の形に効く。
- 人の評価（HUMAN_EVALUATED）のための画像・動画を見て評価する（現在 0 回）。

## D. 注意（守ってほしいこと）

- 試験片は **外形とすき間の感触の確認用**。子どもに触れさせる前に、安全は Engineering の閾値（暫定・SAFETY_UNVERIFIED）で別に見る。
- 共有の作業ツリー（`serpens/`）の `git` の枝を、Design の作業中に切り替えない（Design は `agent/design-floor-watch` の別 worktree で作業）。

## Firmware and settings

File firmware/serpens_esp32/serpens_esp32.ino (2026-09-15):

// Serpens EX-1 駆動リンク ファームウェア（XIAO ESP32S3 / ESP32-S3）
//
// **PC が死んでも、この基板だけでヘビを止める。** それがこのファームの存在理由。
// 仕様は docs/link_protocol.md v2。状態は7つで、判断の順序と時定数は
// serpens/link/device.py（Virtual ESP32）と同じにしてある。
// 参照実装は偽時計で検証済み: tests/test_phase2_*.py / tests/test_phase3_link_robot.py
//
// **HARDWARE_UNVERIFIED**: 実機（ESP32 + STS3215）が無いため、コンパイルも書き込みもしていない。
//   サーボの読み書き（writeServos / readServos）は配線が決まるまで空。README.md 参照。
#include "config.h"
#include "link.h"

// ---- 状態 ----------------------------------------------------------------------------
static DeviceState gState = ST_BOOT;
static StopReason  gReason = SR_BOOT;
static uint16_t    gBootId = 0;
static bool        gTorqueOn = true;      // 起動時は現在姿勢を保持（勝手に脱力しない）
static bool        gBreathing = false;
static float       gTorqueRatio = 1.0f;   // TORQUE 指令（脱力の演出）。安全上限に対する割合

static uint16_t gLastSeq = 0, gLastDriveSeq = 0;
static bool     gHasLastSeq = false;
static uint32_t gHbAt = 0;
static bool     gHbSeen = false;
static uint32_t gDriveAt = 0, gDriveUntil = 0, gHeadUntil = 0, gBodyUntil = 0;
static bool     gDriveSeen = false;
static uint32_t gNonces[16];
static uint8_t  gNonceIdx = 0;
static uint16_t gOverruns = 0, gLoopPeriodUs = CONTROL_PERIOD_MS * 1000;

static float gGoal[N_AXES];               // いまサーボへ書いている角度（指令値）
static float gTarget[N_AXES];             // 補間の目標
static float gSpeed[N_AXES];              // [deg/s]
static float gPhase = 0.0f;               // 歩容の時間位相 [rad]

// サーボから読んだ値（**実測**。指令値と混ぜない）
static float   gMeasPos[N_AXES], gMeasVel[N_AXES], gMeasLoad[N_AXES];
static uint8_t gMeasTemp[N_AXES], gMeasVolt[N_AXES], gMeasFault[N_AXES];
static bool    gMeasOk[N_AXES];

struct DriveCmd { float amp, spatial, freq, gamma; };
static DriveCmd gDrive = {0, 0, 0, 0};

static uint32_t gLastCtrl = 0, gLastTelem = 0;
static FrameReader gRx;

// ---- 小道具 --------------------------------------------------------------------------
static bool driving() { return gState == ST_DRIVING; }

static float clampDeg(int i, float deg) {
  if (deg < JOINTS[i].min_deg) return JOINTS[i].min_deg;
  if (deg > JOINTS[i].max_deg) return JOINTS[i].max_deg;
  return deg;
}

static bool hbFresh(uint32_t now) {
  return gHbSeen && (uint32_t)(now - gHbAt) <= HEARTBEAT_TIMEOUT_MS;
}

static bool anyServoMissing() {
  for (int i = 0; i < N_AXES; i++) if (!gMeasOk[i]) return true;
  return false;
}

// サーボへ 9軸同期書き込み（docs/sts3215_registers.md の 41〜47 ブロック）
// TODO: 配線が決まるまで空。SCServo/ftservo 系ライブラリの SyncWritePosEx を使う予定。
static void writeServos(const float deg[N_AXES]) { (void)deg; }

// サーボから位置・速度・負荷・温度・電圧・fault を読む（56〜63 ブロック）
// TODO: 未実装。読めなかった軸は gMeasOk[i] = false のままにする（**0 で埋めない**）
static void readServos() {
  for (int i = 0; i < N_AXES; i++) gMeasOk[i] = false;
}

static void setTorque(bool on) {
  gTorqueOn = on;
  // TODO: 実機では全軸のトルクスイッチを書く
}

static void setTorqueRatio(float ratio) {
  gTorqueRatio = ratio;
  // TODO: 実機ではトルク制限レジスタ（48番地）へ ratio × 安全上限 を書く
}

static void holdHere() {
  for (int i = 0; i < N_AXES; i++) gTarget[i] = gGoal[i];
}

static void setState(DeviceState to, StopReason reason) {
  gState = to;
  gReason = reason;
  sendEvent(Serial, (uint8_t)gReason, (uint8_t)gState);
}

// 停止。**現在の出力を保持する**（ホーム姿勢へ動かさない）
static void stopMotion(StopReason reason, DeviceState to) {
  if (gState == ST_EMERGENCY_LATCHED && to != ST_EMERGENCY_LATCHED) return;  // ラッチを上書きしない
  gBreathing = false;
  setTorqueRatio(1.0f);                            // 演出の脱力は停止で解除する
  holdHere();
  if (to == ST_TORQUE_DISABLED) setTorque(false);
  setState(to, reason);
}

// ---- 受信 ----------------------------------------------------------------------------
static bool driveOk(const DriveCmd& d, uint16_t ttl) {
  float bodyMax = JOINTS[0].max_deg;
  for (int i = 1; i < N_BODY; i++) if (JOINTS[i].max_deg < bodyMax) bodyMax = JOINTS[i].max_deg;
  return ttl >= 1 && ttl <= DRIVE_TTL_MAX_MS
      && d.amp >= 0.0f && d.amp <= LIMIT_AMPLITUDE_DEG
      && d.spatial > 0.0f && d.spatial <= LIMIT_SPATIAL_DEG
      && fabsf(d.freq) <= LIMIT_TEMPORAL_HZ
      && fabsf(d.gamma) <= LIMIT_GAMMA_DEG
      && d.amp + fabsf(d.gamma) <= bodyMax;        // 合成しても operational limit 内
}

static void handleMotion(uint8_t type, uint16_t seq, uint32_t now) {
  if (!stateArmed(gState)) { sendNack(Serial, seq, type, NACK_DISARMED); return; }
  if (!hbFresh(now))       { sendNack(Serial, seq, type, NACK_NO_HEARTBEAT); return; }

  if (type == CMD_DRIVE) {
    uint16_t ttl = rdU16(gRx.payload);
    DriveCmd d = {rdI16(gRx.payload + 2) / 10.0f, rdI16(gRx.payload + 4) / 10.0f,
                  rdI16(gRx.payload + 6) / 1000.0f, rdI16(gRx.payload + 8) / 10.0f};
    if (!driveOk(d, ttl)) { sendNack(Serial, seq, type, NACK_OUT_OF_RANGE); return; }
    gDrive = d; gDriveAt = now; gDriveSeen = true; gDriveUntil = now + ttl; gLastDriveSeq = seq;
    if (gState != ST_DRIVING) setState(ST_DRIVING, SR_NONE);
    sendAck(Serial, seq, type); return;
  }
  if (type == CMD_HEAD) {
    uint16_t ttl = rdU16(gRx.payload);
    float a[3] = {rdI16(gRx.payload + 2) / 10.0f, rdI16(gRx.payload + 4) / 10.0f,
                  rdI16(gRx.payload + 6) / 10.0f};
    float spd = rdU16(gRx.payload + 8) / 10.0f;
    bool ok = ttl >= 1 && ttl <= DRIVE_TTL_MAX_MS && spd > 0.0f && spd <= LIMIT_HEAD_SPEED_DPS;
    for (int k = 0; k < 3 && ok; k++) {
      const JointCfg& j = JOINTS[N_BODY + k];
      if (a[k] < j.min_deg || a[k] > j.max_deg) ok = false;
    }
    if (!ok) { sendNack(Serial, seq, type, NACK_OUT_OF_RANGE); return; }
    for (int k = 0; k < 3; k++) { gTarget[N_BODY + k] = a[k]; gSpeed[N_BODY + k] = spd; }
    gHeadUntil = now + ttl;
    sendAck(Serial, seq, type); return;
  }
  if (type == CMD_BODY) {
    if (driving()) { sendNack(Serial, seq, type, NACK_BUSY); return; }   // 胴体の持ち主は一つ
    uint16_t ttl = rdU16(gRx.payload);
    float spd = rdU16(gRx.payload + 14) / 10.0f;
    bool ok = ttl >= 1 && ttl <= DRIVE_TTL_MAX_MS && spd > 0.0f && spd <= LIMIT_BODY_SPEED_DPS;
    float a[N_BODY];
    for (int i = 0; i < N_BODY && ok; i++) {
      a[i] = rdI16(gRx.payload + 2 + 2 * i) / 10.0f;
      if (a[i] < JOINTS[i].min_deg || a[i] > JOINTS[i].max_deg) ok = false;
    }
    if (!ok) { sendNack(Serial, seq, type, NACK_OUT_OF_RANGE); return; }
    for (int i = 0; i < N_BODY; i++) { gTarget[i] = a[i]; gSpeed[i] = spd; }
    gBodyUntil = now + ttl;
    sendAck(Serial, seq, type); return;
  }
  if (type == CMD_TORQUE) {
    float ratio = rdU16(gRx.payload) / 1000.0f;
    if (!(ratio > 0.0f && ratio <= 1.0f)) { sendNack(Serial, seq, type, NACK_OUT_OF_RANGE); return; }
    setTorqueRatio(ratio);
    sendAck(Serial, seq, type); return;
  }
  if (type == CMD_POSE) {
    if (gRx.payload[0] != 0 || driving()) { sendNack(Serial, seq, type, NACK_OUT_OF_RANGE); return; }
    for (int i = 0; i < N_AXES; i++) { gTarget[i] = clampDeg(i, HOME_DEG[i]); gSpeed[i] = JOINTS[i].max_speed_dps; }
    sendAck(Serial, seq, type); return;
  }
  if (type == CMD_BREATH) { gBreathing = gRx.payload[0] != 0; sendAck(Serial, seq, type); return; }
  sendNack(Serial, seq, type, NACK_UNKNOWN_CMD);   // 取りこぼしを別の指令として実行しない
}

static void handleFrame(uint32_t now) {
  const uint8_t type = gRx.type;
  const uint16_t seq = gRx.seq;
  if (!gRx.crcOk)                    { sendNack(Serial, seq, type, NACK_BAD_CRC); return; }
  if (gRx.version != LINK_VERSION)   { sendNack(Serial, seq, type, NACK_BAD_VERSION); return; }
  const int want = payloadLenFor(type);
  if (want < 0)                      { sendNack(Serial, seq, type, NACK_UNKNOWN_CMD); return; }
  if (gRx.len != want)               { sendNack(Serial, seq, type, NACK_BAD_LENGTH); return; }
  if (!seqIsForward(seq, gLastSeq, gHasLastSeq)) { sendNack(Serial, seq, type, NACK_STALE_SEQ); return; }
  gLastSeq = seq; gHasLastSeq = true;

  switch (type) {
    case CMD_HEARTBEAT:                              // DRIVE の期限はここでは延びない
      gHbAt = now; gHbSeen = true;
      if (gState == ST_BOOT) setState(ST_DISARMED, SR_BOOT);
      sendAck(Serial, seq, type); return;
    case CMD_PING: sendAck(Serial, seq, type); return;
    case CMD_EMERGENCY:
      stopMotion(SR_EMERGENCY_CMD, ST_EMERGENCY_LATCHED); sendAck(Serial, seq, type); return;
    case CMD_STOP:
      stopMotion(SR_OPERATOR_STOP, gRx.payload[0] == 1 ? ST_TORQUE_DISABLED : ST_DISARMED);
      sendAck(Serial, seq, type); return;
    case CMD_CLEAR_FAULT: {
      uint32_t nonce = rdU32(gRx.payload);
      for (int i = 0; i < 16; i++) if (gNonces[i] == nonce) { sendNack(Serial, seq, type, NACK_NONCE_REUSED); return; }
      gNonces[gNonceIdx] = nonce; gNonceIdx = (gNonceIdx + 1) % 16;
      setTorque(true);
      setState(ST_DISARMED, gReason);                // **待機へ戻すだけ。走行は再開しない**
      sendAck(Serial, seq, type); return;
    }
    default: break;
  }
  if (gState == ST_EMERGENCY_LATCHED) { sendNack(Serial, seq, type, NACK_LATCHED); return; }
  if (type == CMD_DISARM) { stopMotion(SR_OPERATOR_STOP, ST_DISARMED); sendAck(Serial, seq, type); return; }
  if (type == CMD_ARM) {
    // **どの起動の機体を ARM するのかを名指しさせる。** 再起動とすれ違った ARM は通らない
    if (rdU16(gRx.payload) != gBootId) { sendNack(Serial, seq, type, NACK_STALE_BOOT); return; }
    if (gState == ST_FAULT_HOLD) { sendNack(Serial, seq, type, NACK_BUSY); return; }
    if (!hbFresh(now))           { sendNack(Serial, seq, type, NACK_NO_HEARTBEAT); return; }
    setTorque(true);
    setState(ST_ARMED_HOLD, SR_NONE);
    sendAck(Serial, seq, type); return;
  }
  if (type == CMD_LIMITS) { sendNack(Serial, seq, type, NACK_UNKNOWN_CMD); return; }  // Phase 9
  handleMotion(type, seq, now);
}

// ---- watchdog（PC が死んでも自分で止まる） -----------------------------------------------
static void watchdogs(uint32_t now) {
  uint8_t maxTemp = 0;
  bool anyFault = false;
  for (int i = 0; i < N_AXES; i++) {
    if (!gMeasOk[i]) continue;
    if (gMeasTemp[i] > maxTemp) maxTemp = gMeasTemp[i];
    if (gMeasFault[i]) anyFault = true;
  }
  if (maxTemp > FAULT_TEMP_LIMIT_C)  { stopMotion(SR_OVERHEAT, ST_EMERGENCY_LATCHED); return; }
  if (anyFault)                      { stopMotion(SR_SERVO_FAULT, ST_EMERGENCY_LATCHED); return; }
  if (stateArmed(gState) && anyServoMissing()) { stopMotion(SR_SERVO_FAULT, ST_FAULT_HOLD); return; }
  if (gHbSeen && !hbFresh(now) && stateArmed(gState)) {
    stopMotion(SR_HEARTBEAT_LOST, ST_FAULT_HOLD); return;     // USB 断・PC 強制終了もここ
  }
  if (gState == ST_FAULT_HOLD && hbFresh(now) && !anyServoMissing()) {
    setState(ST_DISARMED, gReason); return;                   // 復帰は待機まで
  }
  if (driving() && (int32_t)(now - gDriveUntil) > 0) {
    stopMotion(SR_DRIVE_TTL, ST_ARMED_HOLD); return;          // 保持のまま（条件 4）
  }
  if (gState == ST_ARMED_HOLD && gDriveSeen && (uint32_t)(now - gDriveAt) > DRIVE_DISARM_MS) {
    stopMotion(SR_DRIVE_TTL, ST_DISARMED); return;
  }
  if ((int32_t)(now - gHeadUntil) > 0) for (int k = 0; k < 3; k++) gTarget[N_BODY + k] = gGoal[N_BODY + k];
  if ((int32_t)(now - gBodyUntil) > 0 && !driving()) for (int i = 0; i < N_BODY; i++) gTarget[i] = gGoal[i];
}

// ---- 制御（100Hz） --------------------------------------------------------------------
static void control(uint32_t now) {
  uint32_t dtMs = now - gLastCtrl;
  gLastCtrl = now;
  gLoopPeriodUs = (uint16_t)(dtMs * 1000 > AGE_MAX_MS ? AGE_MAX_MS : dtMs * 1000);
  if (dtMs > CONTROL_PERIOD_MS * 3 / 2) gOverruns++;
  float dt = dtMs / 1000.0f;
  if (driving()) {
    gPhase += 2.0f * PI * gDrive.freq * dt;
    float big = gDrive.spatial * PI / 180.0f;
    for (int n = 0; n < N_BODY; n++) {                       // α(n,t) = A·sin(Ω·n+ω·t) + γ0·n/N
      float a = gDrive.amp * sinf(big * n + gPhase) + gDrive.gamma * n / (float)(N_BODY - 1);
      gGoal[n] = clampDeg(n, a);
    }
  }
  for (int i = 0; i < N_AXES; i++) {
    if (driving() && i < N_BODY) continue;
    float step = gSpeed[i] * dt;
    float diff = clampDeg(i, gTarget[i]) - gGoal[i];
    if (diff > step) diff = step;
    if (diff < -step) diff = -step;
    gGoal[i] += diff;
  }
  if (gTorqueOn) writeServos(gGoal);                         // 保持中も送り続ける
  readServos();                                              // 実測値を取り込む
}

static uint16_t ageMs(uint32_t at, bool seen, uint32_t now) {
  if (!seen) return AGE_MAX_MS;
  uint32_t d = now - at;
  return (uint16_t)(d > AGE_MAX_MS ? AGE_MAX_MS : d);
}

static void sendTelemetry(uint32_t now) {
  uint8_t p[MAX_PAYLOAD];
  int o = 0;
  putU16(p, o, gBootId);
  uint32_t up = now;
  p[o++] = up & 0xFF; p[o++] = (up >> 8) & 0xFF; p[o++] = (up >> 16) & 0xFF; p[o++] = (up >> 24) & 0xFF;
  p[o++] = (uint8_t)gState;
  p[o++] = (uint8_t)gReason;
  putU16(p, o, gLastSeq);
  putU16(p, o, gLastDriveSeq);
  uint16_t fl = 0;
  if (driving()) fl |= FL_DRIVING;
  if (gBreathing) fl |= FL_BREATHING;
  if (hbFresh(now)) fl |= FL_HEARTBEAT_OK;
  if (driving() && (int32_t)(now - gDriveUntil) <= 0) fl |= FL_DRIVE_VALID;
  if (gTorqueOn) fl |= FL_TORQUE_ON;
  if (stateArmed(gState)) fl |= FL_ARMED;
  if (gState == ST_EMERGENCY_LATCHED) fl |= FL_EMERGENCY_LATCHED;
  if (anyServoMissing()) fl |= FL_SERVO_MISSING;
  if (gOverruns) fl |= FL_OVERRUN;
  putU16(p, o, fl);                                          // **FL_SIMULATED は実機では立てない**
  putU16(p, o, ageMs(gHbAt, gHbSeen, now));
  putU16(p, o, ageMs(gDriveAt, gDriveSeen, now));
  putU16(p, o, (driving() && (int32_t)(gDriveUntil - now) > 0) ? (uint16_t)(gDriveUntil - now) : 0);
  putU16(p, o, gLoopPeriodUs);
  putU16(p, o, gOverruns);
  p[o++] = (uint8_t)SRC_HARDWARE;                            // **実機の値**
  int nAxes = 0;
  for (int i = 0; i < N_AXES; i++) if (gMeasOk[i]) nAxes++;
  p[o++] = (uint8_t)nAxes;
  for (int i = 0; i < N_AXES; i++) {
    if (!gMeasOk[i]) continue;                               // 読めない軸は返さない（0 で埋めない）
    int16_t pos = (int16_t)lroundf(gMeasPos[i] * 10.0f);
    int16_t vel = (int16_t)lroundf(gMeasVel[i] * 10.0f);
    int16_t load = (int16_t)lroundf(gMeasLoad[i] * 1000.0f);
    p[o++] = pos & 0xFF; p[o++] = (pos >> 8) & 0xFF;
    p[o++] = vel & 0xFF; p[o++] = (vel >> 8) & 0xFF;
    p[o++] = load & 0xFF; p[o++] = (load >> 8) & 0xFF;
    p[o++] = gMeasTemp[i];
    p[o++] = gMeasVolt[i];
    p[o++] = gMeasFault[i];
    p[o++] = 0xFF; p[o++] = 0xFF;                            // current 不明（電流センサ無し）
  }
  sendFrame(Serial, REP_TELEMETRY, p, (uint8_t)o);
}

// ---- Arduino --------------------------------------------------------------------------
void setup() {
  Serial.begin(921600);                                      // ネイティブ USB CDC（速度は無視される）
  gBootId = (uint16_t)(esp_random() & 0xFFFF);               // 起動ごとに変える（PC が再起動に気付く）
  for (int i = 0; i < N_AXES; i++) {
    gGoal[i] = HOME_DEG[i];                                  // TODO: 実機では現在角を読んでから入れる
    gTarget[i] = gGoal[i];
    gSpeed[i] = JOINTS[i].max_speed_dps;
    gMeasOk[i] = false;
  }
  gState = ST_BOOT; gReason = SR_BOOT;                       // **必ず BOOT から始まる**
  gLastCtrl = millis(); gLastTelem = gLastCtrl;
}

void loop() {
  uint32_t now = millis();
  while (Serial.available()) {
    if (gRx.feed((uint8_t)Serial.read())) handleFrame(millis());
  }
  watchdogs(now);
  if ((uint32_t)(now - gLastCtrl) >= CONTROL_PERIOD_MS) control(now);
  if ((uint32_t)(now - gLastTelem) >= TELEMETRY_PERIOD_MS) { gLastTelem = now; sendTelemetry(now); }
}

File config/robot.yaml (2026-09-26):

# Serpens EX-1 設定ファイル
# 寸法・しきい値・ゲインはすべてここに書く。コードに数値を直書きしない。
# 単位はキー名の接尾辞で示す: _mm, _deg, _s, _hz, _c(℃), _v, _g, _dps(°/s), _dps2(°/s²)
# 「仮」と書いた値は未確定。実機を見て必ず見直すこと。

# ---------------------------------------------------------------------------
# 機体寸法（確定値）
# 原点 = 尾端、+x が頭方向、単位 mm
# ---------------------------------------------------------------------------
body:
  length_mm: 850
  diameter_mm: 50
  mass_g: 1000
  tail_x_mm: 0
  head_tip_x_mm: 850

# 関節。x_mm は尾端からの位置。axis は yaw(水平) / pitch(持ち上げ) / roll(かしげ)。
#   servo_id        バス上の ID
#   direction       取り付け向き（+1 / -1）
#   horn_offset_deg サーボホーン取付角のずれ（実機で測って吸収する。既定 0）
#   max_speed_dps   その軸の最高角速度（頭部は丁寧に動かすため遅い）
#
# **可動域は意味の違う3つを別々に持つ**（joint_limit_policy に状態と出典）。
#   onset_deg / onset_collides_deg
#       geometry_collision_onset。CAD nominal geometry で干渉が始まる境界の bracket。
#       **指令のクランプ値として使わない。** 64.8° は干渉なし、64.9° で干渉（R03 検査姿勢）
#   mechanical_min/max_deg
#       mechanical_design_limit。**PROVISIONAL**（ケーブル経路が不合格のため確定していない）
#   min_deg / max_deg
#       software_operational_limit。**CONDITIONAL**。指令はここでクランプする。
#       物理試験へ進むための候補値であって、実機で許可された値ではない
#
# 実機の 9軸構成（コードから確認。2026-09-16）: 胴体ヨー J1〜J6 / 首ピッチ J7 / 頭ヨー J8 / 頭ロール J9。
# **胴体に pitch 軸は無い**（垂直波＝螺旋歩容を作れない）
# TODO: 外皮ニット装着後に可動範囲を再測定する（README 参照）
joints:
  - {name: J1, servo_id: 1, axis: yaw,   x_mm: 100, direction: 1, horn_offset_deg: 0.0, onset_deg: 64.8, onset_collides_deg: 64.9, mechanical_min_deg: -55.0, mechanical_max_deg: 55.0, min_deg: -50.0, max_deg: 50.0, max_speed_dps: 240.0}
  - {name: J2, servo_id: 2, axis: yaw,   x_mm: 195, direction: 1, horn_offset_deg: 0.0, onset_deg: 64.8, onset_collides_deg: 64.9, mechanical_min_deg: -55.0, mechanical_max_deg: 55.0, min_deg: -50.0, max_deg: 50.0, max_speed_dps: 240.0}
  - {name: J3, servo_id: 3, axis: yaw,   x_mm: 290, direction: 1, horn_offset_deg: 0.0, onset_deg: 64.8, onset_collides_deg: 64.9, mechanical_min_deg: -55.0, mechanical_max_deg: 55.0, min_deg: -50.0, max_deg: 50.0, max_speed_dps: 240.0}
  - {name: J4, servo_id: 4, axis: yaw,   x_mm: 385, direction: 1, horn_offset_deg: 0.0, onset_deg: 64.8, onset_collides_deg: 64.9, mechanical_min_deg: -55.0, mechanical_max_deg: 55.0, min_deg: -50.0, max_deg: 50.0, max_speed_dps: 240.0}
  - {name: J5, servo_id: 5, axis: yaw,   x_mm: 480, direction: 1, horn_offset_deg: 0.0, onset_deg: 64.8, onset_collides_deg: 64.9, mechanical_min_deg: -55.0, mechanical_max_deg: 55.0, min_deg: -50.0, max_deg: 50.0, max_speed_dps: 240.0}
  - {name: J6, servo_id: 6, axis: yaw,   x_mm: 575, direction: 1, horn_offset_deg: 0.0, onset_deg: 64.8, onset_collides_deg: 64.9, mechanical_min_deg: -55.0, mechanical_max_deg: 55.0, min_deg: -50.0, max_deg: 50.0, max_speed_dps: 240.0}
  - {name: J7, servo_id: 7, axis: pitch, x_mm: 670, direction: 1, horn_offset_deg: 0.0, onset_deg: null, onset_collides_deg: null, mechanical_min_deg: -10.0, mechanical_max_deg: 95.0, min_deg: -8.0,  max_deg: 90.0, max_speed_dps: 120.0}
  - {name: J8, servo_id: 8, axis: yaw,   x_mm: 725, direction: 1, horn_offset_deg: 0.0, onset_deg: null, onset_collides_deg: null, mechanical_min_deg: -85.0, mechanical_max_deg: 85.0, min_deg: -80.0, max_deg: 80.0, max_speed_dps: 90.0}
  - {name: J9, servo_id: 9, axis: roll,  x_mm: 765, direction: 1, horn_offset_deg: 0.0, onset_deg: null, onset_collides_deg: null, mechanical_min_deg: -40.0, mechanical_max_deg: 40.0, min_deg: -35.0, max_deg: 35.0, max_speed_dps: 90.0}

# ---------------------------------------------------------------------------
# 可動域の状態と出典（CAD 側の最新提案。2026-09-16）
# **どれも実機で確かめていない。** software_operational_limit は「物理試験へ進むための候補」
# ---------------------------------------------------------------------------
joint_limit_policy:
  cad_sources: [Serpens_BELLY_R03_TWO_LINK_REVIEW, Serpens_R03_COUPON_CABLE_PREP]
  status:
    geometry_collision_onset: CAD_VERIFIED    # nominal geometry のみ。実物・ケーブル込みではない
    mechanical_design_limit: PROVISIONAL      # ±55°（暫定）
    software_operational_limit: CONDITIONAL   # ±50°（条件つき候補）
  verified_in_cad: true
  verified_with_cable: false                  # Cable Routing が不合格
  verified_with_hardware: false               # 実機ゼロ
  onset_bracket_deg: [64.8, 64.9]             # この間で干渉が始まる（64.8 なし / 64.9 あり）
  # **clamp に使ってよいのは software_operational_limit だけ。**
  clamp_source: software_operational_limit

# 首（J7）の使い分け
neck:
  look_min_deg: 55.0        # 人を見るときの J7 下限
  look_max_deg: 65.0        # 人を見るときの J7 上限（これ以上倒すと J8 が世界座標で roll になる）
  full_rear_min_deg: 85.0   # 「真上から見下ろすフル鎌首」演出専用の範囲
  full_rear_max_deg: 90.0

# 質量配分（仮定値。実測したら差し替える）
mass_budget_g:
  servo_each: 55
  servo_count: 9
  segment_frame_each: 30
  segment_frame_count: 8
  passive_wheels_total: 60      # 受動輪 + ベアリング
  head_total: 90                # シェル + XIAO + ToF + LED
  skin_and_wiring: 115
  neck_lifted_mass: 200         # J7 が持ち上げる質量
  neck_lifted_cog_mm: 104       # J7 から重心までの距離
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

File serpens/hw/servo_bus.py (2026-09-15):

"""サーボバスの抽象インターフェース。

上位層（モーション・行動）は必ずこのクラス経由でサーボを操作する。
実装は MockServoBus（シミュレーション）と FeetechServoBus（実機）の2つで、
コマンドライン引数 `--bus mock|feetech` で差し替える（make_bus を参照）。

角度は「関節角」[deg] で扱う。0° = まっすぐ（ホーム姿勢）。
取り付け向き・組立オフセット・ステップ変換は各実装の内部で処理する。
"""
from __future__ import annotations

from abc import ABC, abstractmethod
from dataclasses import dataclass
from typing import Any, NamedTuple


class ServoState(NamedTuple):
    """read_state() の戻り値。タプルとしても (pos, load, volt, temp) で展開できる。"""

    pos_deg: float   # 関節角 [deg]
    load: float      # 負荷率（1.0 = 100%）
    volt: float      # 電源電圧 [V]
    temp_c: float    # 内部温度 [℃]


@dataclass(frozen=True)
class Goal:
    """1軸分の目標指令。"""

    deg: float          # 目標関節角 [deg]
    speed_dps: float    # 最大速度 [deg/s]
    accel_dps2: float   # 加減速度 [deg/s²]


@dataclass(frozen=True)
class JointSpec:
    """設定ファイルから読んだ1関節分の仕様。"""

    name: str
    servo_id: int
    axis: str
    x_mm: float
    direction: int
    horn_offset_deg: float   # サーボホーン取付角のずれ（サーボ角 = direction×関節角 + これ）
    min_deg: float           # ソフトリミット
    max_deg: float
    mech_min_deg: float      # mechanical_design_limit（PROVISIONAL）
    mech_max_deg: float
    max_speed_dps: float

    @staticmethod
    def from_cfg(d: dict[str, Any]) -> "JointSpec":
        """config の joints 要素から生成する。ソフトリミットが機械リミットの内側か確認する。"""
        j = JointSpec(
            name=str(d["name"]), servo_id=int(d["servo_id"]), axis=str(d["axis"]),
            x_mm=float(d["x_mm"]), direction=int(d["direction"]),
            horn_offset_deg=float(d["horn_offset_deg"]),
            min_deg=float(d["min_deg"]), max_deg=float(d["max_deg"]),
            mech_min_deg=float(d["mechanical_min_deg"]), mech_max_deg=float(d["mechanical_max_deg"]),
            max_speed_dps=float(d["max_speed_dps"]),
        )
        if not j.mech_min_deg <= j.min_deg < j.max_deg <= j.mech_max_deg:
            raise ValueError(f"{j.name}: ソフトリミットが機械リミットの外にあります")
        return j


class ServoCommError(RuntimeError):
    """サーボとの通信に失敗した。"""


class ServoBus(ABC):
    """サーボバスの抽象クラス。

    公開メソッド（set_goal など）はソフトウェアリミットでのクランプを共通で行い、
    実際の送信はサブクラスの `_xxx` メソッドが担当する（テンプレートメソッド）。
    """

    def __init__(self, cfg: dict[str, Any]) -> None:
        self.cfg = cfg
        self.joints: dict[int, JointSpec] = {
            j.servo_id: j for j in (JointSpec.from_cfg(d) for d in cfg["joints"])
        }
        # トルクの上限（ストールトルクに対する比）。**出どころは REFERENCE 値で、実測ではない**
        # （safety_limits.torque。measured_safe_torque_nm が埋まるまで暫定）
        self.torque_ceiling = float(cfg["safety_limits"]["torque"]["software_torque_limit_ratio"])
        self.torque_ceiling_applied = False

    # ---- 共通処理 ------------------------------------------------------------
    @property
    def ids(self) -> list[int]:
        """設定されているサーボ ID（関節順）。"""
        return list(self.joints.keys())

    def clamp_deg(self, servo_id: int, deg: float) -> float:
        """関節のソフトウェアリミットに収める。"""
        j = self.joints[servo_id]
        return min(max(deg, j.min_deg), j.max_deg)

    def set_goal(self, servo_id: int, deg: float, speed_dps: float, accel: float) -> None:
        """目標角を指令する。accel は加減速度 [deg/s²]。"""
        self._set_goals({servo_id: Goal(self.clamp_deg(servo_id, deg), speed_dps, accel)})

    def sync_set_goals(self, goals: dict[int, Goal]) -> None:
        """複数軸の目標を同時に指令する。"""
        clamped = {
            sid: Goal(self.clamp_deg(sid, g.deg), g.speed_dps, g.accel_dps2)
            for sid, g in goals.items()
        }
        self._set_goals(clamped)

    def read_state(self, servo_id: int) -> ServoState:
        """1軸の状態を読む。失敗したら ServoCommError。"""
        states = self._read_states([servo_id])
        if servo_id not in states:
            raise ServoCommError(f"サーボ ID {servo_id} の状態を読めませんでした")
        return states[servo_id]

    def sync_read_states(self, ids: list[int] | None = None) -> dict[int, ServoState]:
        """複数軸の状態を読む。読めなかった軸は結果に含まれない。"""
        return self._read_states(list(ids) if ids is not None else self.ids)

    def read_positions(self, ids: list[int] | None = None) -> dict[int, float]:
        """位置だけを読む [deg]。実装によってはこちらの方が速い。"""
        return {sid: st.pos_deg for sid, st in self.sync_read_states(ids).items()}

    @property
    def fast_reads(self) -> bool:
        """一括読み出しが使えるなら True（読み出し頻度の選択に使う）。"""
        return True

    # ---- レジスタ単位（実機のセットアップ用。docs/sts3215_registers.md を参照） ----
    def read_register(self, servo_id: int, addr: int, size: int) -> int | None:
        """レジスタを読む。読めなければ None。"""
        raise NotImplementedError

    def write_register(self, servo_id: int, addr: int, size: int, value: int, eeprom: bool = False) -> bool:
        """レジスタを書く。eeprom=True なら書き込みロックを外してから書き、書いたら戻す。"""
        raise NotImplementedError

    def scan(self, ids: list[int] | None = None) -> list[int]:
        """応答する ID を探す。"""
        return [sid for sid in (ids if ids is not None else self.ids) if self.ping(sid)]

    def set_servo_id(self, old_id: int, new_id: int) -> bool:
        """ID を変更する（EEPROM）。"""
        raise NotImplementedError

    def supports_sync_read(self) -> bool:
        """SYNC READ に応答するか実際に試す。"""
        return len(self.sync_read_states(self.ids[:2])) == min(2, len(self.ids))

    # ---- 実装が必要なもの ----------------------------------------------------
    @abstractmethod
    def connect(self) -> None:
        """バスに接続する。"""

    @abstractmethod
    def disconnect(self, torque_off: bool = True) -> None:
        """バスから切断する。

        torque_off=False なら**トルクを入れたまま**閉じる（姿勢を保持して終わりたいとき）。
        どちらが安全かは自重と頭部の支持で決まるので実機で確認すること（**未検証**）。
        """

    @abstractmethod
    def ping(self, servo_id: int) -> bool:
        """サーボが応答すれば True。"""

    @abstractmethod
    def set_torque(self, servo_id: int, on: bool) -> None:
        """トルクの ON/OFF。"""

    def set_torque_limit(self, servo_id: int, ratio: float) -> None:
        """出力トルクの上限。**ratio 1.0 = 安全上限**（safety_limits.torque.software_torque_limit_ratio）。

        脱力演出はこの上限に対する割合で、ここを通して全力へ戻すことはできない。
        """
        self._set_torque_limit(servo_id, min(max(ratio, 0.0), 1.0) * self.torque_ceiling)

    def apply_torque_ceiling(self) -> list[int]:
        """全軸へ安全上限を書き、**書けなかった軸の ID** を返す。

        接続のたびに通す（SRAM なので電源で消える）。書けなかった軸があるまま走らせない
        （`autonomy_blockers` が実機の自律走行を止める）。
        """
        failed: list[int] = []
        for sid in self.ids:
            try:
                self._set_torque_limit(sid, self.torque_ceiling)
            except (ServoCommError, OSError):
                failed.append(sid)
        self.torque_ceiling_applied = not failed
        return failed

    def _set_torque_limit(self, servo_id: int, ratio: float) -> None:
        """実際に上限を書く（ストールトルクに対する割合）。実装側で上書きする。"""

    @abstractmethod
    def _set_goals(self, goals: dict[int, Goal]) -> None:
        """クランプ済みの目標を送信する。"""

    @abstractmethod
    def _read_states(self, ids: list[int]) -> dict[int, ServoState]:
        """状態を読み出す。"""
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

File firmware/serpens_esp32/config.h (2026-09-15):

// Serpens EX-1 機体側の定数。**config/robot.yaml の link 節と同じ値を手で写す。**
// ここを変えたら robot.yaml も直すこと（食い違うと PC の表示と機体の挙動がずれる）。
// 出典: docs/link_protocol.md §5、config/robot.yaml の joints / link
#pragma once

#include <stdint.h>

// ---- 時間（docs/link_protocol.md §5。すべて要実測で確定する） ----
static const uint32_t HEARTBEAT_TIMEOUT_MS = 400;   // これだけ heartbeat が来なければ停止
static const uint32_t DRIVE_TTL_MAX_MS     = 1000;  // 受け付ける TTL の上限
static const uint32_t DRIVE_DISARM_MS      = 2000;  // 保持のまま放置したら待機へ
static const uint32_t CONTROL_PERIOD_MS    = 10;    // 100Hz
static const uint32_t TELEMETRY_PERIOD_MS  = 100;   // 10Hz

// ---- 指令値の絶対上限（PC の設定では緩められない） ----
static const float LIMIT_AMPLITUDE_DEG   = 40.0f;
static const float LIMIT_SPATIAL_DEG     = 150.0f;
static const float LIMIT_TEMPORAL_HZ     = 1.0f;
static const float LIMIT_GAMMA_DEG       = 30.0f;
static const float LIMIT_HEAD_SPEED_DPS  = 120.0f;
static const float LIMIT_BODY_SPEED_DPS  = 240.0f;  // BODY 指令（とぐろ・鎌首）の速度上限

// ---- 異常で緊急停止（ラッチ）する条件 ----
static const uint8_t FAULT_TEMP_LIMIT_C = 60;       // behavior.safety.overheat_c(55) より上

// ---- 関節（config/robot.yaml の joints と同じ順・同じ値） ----
#define N_AXES 9
#define N_BODY 6                                    // J1..J6 が歩容に使う胴体ヨー

struct JointCfg {
  uint8_t servo_id;
  float   min_deg;
  float   max_deg;
  float   max_speed_dps;
  int8_t  direction;
  float   horn_offset_deg;                          // 実機で測って入れる（既定 0）
};

static const JointCfg JOINTS[N_AXES] = {
  // **software_operational_limit**（config/robot.yaml の min/max_deg。CONDITIONAL）。
  // CAD R03: 干渉の始まりは 64.8〜64.9°、mechanical_design_limit は ±55°（PROVISIONAL）
  {1,  -50.0f,  50.0f, 240.0f, 1, 0.0f}, // J1 尾側
  {2,  -50.0f,  50.0f, 240.0f, 1, 0.0f},
  {3,  -50.0f,  50.0f, 240.0f, 1, 0.0f},
  {4,  -50.0f,  50.0f, 240.0f, 1, 0.0f},
  {5,  -50.0f,  50.0f, 240.0f, 1, 0.0f},
  {6,  -50.0f,  50.0f, 240.0f, 1, 0.0f}, // J6 頭側の胴体ヨー
  {7,   -8.0f,  90.0f, 120.0f, 1, 0.0f}, // J7 首 pitch
  {8,  -80.0f,  80.0f,  90.0f, 1, 0.0f}, // J8 頭 yaw
  {9,  -35.0f,  35.0f,  90.0f, 1, 0.0f}, // J9 頭 roll
};

// 起動時の姿勢（config/robot.yaml の poses.home）。J7 = +8° は呼吸が下限で切れないため
static const float HOME_DEG[N_AXES] = {0.0f, 0.0f, 0.0f, 0.0f, 0.0f, 0.0f, 8.0f, 0.0f, 0.0f};

// ---- サーボ（docs/sts3215_registers.md） ----
static const uint32_t SERVO_BAUD      = 1000000;    // TTL バス
// サーボ: FEETECH STS3215-C044（7.4V / 1:191）。**未購入・未実測**
static const int      STEPS_PER_REV   = 4096;
static const int      CENTER_STEP     = 2047;

// ---- 配線（**未確定。実機を組む人が決めて、ここに書く**） ----
// TODO: 駆動リンク用 ESP32-S3 と サーボバスの結線が未定。以下は仮の名前だけ置いてある。
//   - 頭部センサ用の XIAO ESP32S3 と同じ基板にするのか、別基板にするのか
//   - サーボの半二重 TTL をどう作るのか（Waveshare Bus Servo Adapter を挟むのか、
//     方向制御ピン付きのトランシーバを載せるのか）
// 決まるまでフラッシュしないこと。
#define SERVO_UART_NUM   1
#define SERVO_TX_PIN     -1                         // TODO
#define SERVO_RX_PIN     -1                         // TODO
#define SERVO_DIR_PIN    -1                         // TODO（不要な回路なら -1 のまま）

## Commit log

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2026-09-11 STEP2: サーボ抽象層とモックを追加
    - ServoBus 抽象クラス（関節角 deg、ソフトウェアリミットで共通クランプ）
    - MockServoBus: 一次遅れ追従、負荷・温度・電圧の模擬（温度時定数は config）
    - FeetechServoBus: ftservo-python-sdk 使用、実機テスト未実施
    - head_io: 頭部シリアルプロトコル（SerialHeadIO 自動再接続 / MockHeadIO）
    - docs/sts3215_registers.md: 公式資料から確認したレジスタ表
    - テスト 39 件（パケットはプロトコル資料の実例と照合）。conftest の 0件読み替えを削除
    [robot.yaml]
2026-09-11 STEP3: 歩容エンジン・姿勢・アニメーターを追加
    - gait: α(n,t)=A_n·sin(Ωn+ωt)+γ、振幅勾配と旋回オフセット、開始/停止ブレンド
    - poses: home / coil / rear_up / full_rear_up / head_look / relax（J9 は roll）
    - animator: 3種の補間、呼吸オーバーレイ、freeze、最高角速度による時間延長
    - kinematics: 3D 順運動学と自己干渉チェック（とぐろの干渉なしを検証）
    - config: 関節間隔・質量配分・首の使い分けしきい値
    [robot.yaml]
2026-09-11 STEP4: 2Dシミュレータを追加
    - sim/world.py: 受動輪の非ホロノミック拘束を最小二乗で解いて胴体速度を求める
    - 浮いたリンクは拘束しない、マット外へ出ないようクランプ
    - tangential_drag_ratio（接線方向の転がり抵抗、既定 0 = 指定どおりのモデル）
    - tools/sim_view.py: 上から見た図・GIF と、歩容ごとの 1周期あたり前進量
    - テスト 70 件
    [robot.yaml]
2026-09-11 STEP4: レビュー回答を反映
    - 旋回入力を γ に一本化（振幅勾配を削除）、head_weighted を既定、γ は1周期でランプ
    - とぐろを尾から順に巻く（stagger キーフレーム）、ソフトリミット ±85° 内で再計算（329°巻き）
    - 機械/ソフトリミット、ホーン取付角オフセット、軸別の最高角速度
    - 車輪 7リンク×2 = 14輪、頭部は等方摩擦パッド、tangential_drag_ratio = 0.02（要実機校正）
    - θ_body（生値+1周期ローパス）/ θ_head、首マーカは J7 より胴体側
    - J7 ホーム +8°、鎌首の土台 s_curve / partial_coil
    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
    [robot.yaml]
2026-09-11 STEP4.5: Sim-to-Real 校正の器を追加
    - tools/fit_sim.py: 実測 CSV から tangential_drag_ratio を床材ごとに同定、比較グラフ
    - data/real_runs.csv: 列の定義とダミー1行
    - sim/measure.py: 1周期あたり前進量の測定を共通化
    [real_runs.csv, robot.yaml]
2026-09-11 STEP5: 知覚（ArUco・ホモグラフィ・人物追跡）を追加
    - homography: 四隅4点、JSON 保存、マーカ高さの視差補正
    - aruco_locator: 首/尾マーカ → SnakePoseTracker（θ_body は1周期の移動平均）
    - person_detector: YOLO（CPU, person, 重みは手動配置）+ 最寄り1人の追跡（2秒ヒステリシス、3秒保持、1.5m 範囲）
    - sim/virtual_camera: 実機なしで知覚を通しで試す仮想カメラ
    - tools: make_aruco / calibrate_floor / perception_demo / perception_live
    [robot.yaml]
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2026-09-11 STEP6: 内部状態と行動を追加
    - internal_state: 一次遅れの内部状態、Energy はサーボ温度から
    - utility / fsm: 9状態の効用（±8%乱数）、ヒステリシス1.15倍・最小継続4秒、PETTED 割り込み
    - controller: 目標点→γと周波数、1m以内8cm/s（気づく前も）、400mm停止（惰性込み）、マット端の向き直り
    - expression: 反応遅延・驚きの全停止・オーバーシュート・かしげ・よそ見・脱力
    - brain / sim/session: 全体をつなぐ中枢と、実機なしで動かすセッション
    - gait: γ0 を速さ制限つきで追従（毎周期の目標変更でも滑らか）
    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
    [robot.yaml]
2026-09-12 STEP6: 安全割り込みと展示レイアウトの変更を反映
    - 割り込みの優先度を safety > PETTED > ALERT > 効用 に
    - 安全: 過熱で COIL_REST_HEAT（60秒・割り込み不可）、掴まれたら PETTED、400mm 停止は常時+即時停止
    - COIL_REST を HEAT / MOOD に分割（MOOD は人が来たら ALERT へ抜ける）
    - 展示レイアウト: 来場者は y<0 の1辺のみ、カメラは奥 (600,1370,1100)、台の高さ600mm、縁20mm R10
    - マーカ 50mm・台座60mm角・艶消し、人の検出は来場者側のみ
    - 仮想フェンス: 頭先端で判定し、端では後退しながら中央へ向き直る（最小継続時間つき）
    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
    [robot.yaml]
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2026-09-12 YOLO の重みを配置し、オフライン起動を検証
    - models/yolo11n.pt（5,613,764B, SHA256 0ebbc80d…, 2026-09-12 取得。git には入れない）
    - 自動ダウンロード・自動更新を無効化（YOLO_AUTOINSTALL / YOLO_OFFLINE / YOLO_HUB_OFFLINE）
    - tools/offline_check.py: ネットワーク遮断下でアプリが最後まで動くか確認
    - tests/test_offline.py: 遮断下で重み読み込み + 推論（bus.jpg で4人検出）
    - person.detect_hz / imgsz を config 化（推論が制御周期に与える影響を調整）
    [robot.yaml]
2026-09-12 STEP8: 実機用の対話式ツール servo_setup.py を追加
    - hw/registers.py: 資料どおりのレジスタ定義（初期値・単位・EEPROM 領域）
    - ServoBus に read_register / write_register / scan / set_servo_id / supports_sync_read
    - MockServoBus がレジスタを再現（最高入力電圧 8.0V の罠、EEPROM ロック、負荷の符号ビット）
    - FeetechServoBus は EEPROM 書き込み時にトルクOFF→ロック解除→書く→ロック
    - tools/servo_setup.py: 8メニュー（ポート/スキャン/電圧設定/ID一括/ライブ表示/符号検証/SYNC READ/中立保持）
    - モック相手に全メニューを通すテスト（137件すべて成功）
    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
    [robot.yaml]
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2026-09-12 Phase1: 実機接続の配線・停止の分離・終了処理を修正
    報告書の指摘を実コードで再現確認してから修正（実機は動かしていない）。
    1. 参照の不一致
    - SimSession に bus / head を注入（監視・指令・トルク操作が同じ接続先を参照）
    - app.build は実機バスと頭部をセッションより先に作る。session.bus の差し替えをやめた
    - 実機経路で MockHeadIO を実センサーとして使わない（未接続なら None、--head-port で実接続）
    2. 停止の分離（serpens/safety.py 新規）
    - RUN / HOLD（通常停止・姿勢保持）/ DISABLED（明示の脱力）/ EMERGENCY（ラッ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
    [robot.yaml]
2026-09-12 Phase2: PC⇄ESP32 駆動リンク（機体側watchdogと緊急停止ラッチ）を追加
    - docs/link_protocol.md: フレーム・指令・状態機械・不変条件の契約を定義
    - serpens/link/: protocol/messages（フレーム）、device/device_motion（機体側の参照実装）、
    client（PC側）、transport（偽経路: USB抜去・PC強制終了・再起動・重複・CRC破損）、harness
    - firmware/serpens_esp32/: 参照実装を写したスケッチ。**未コンパイル・未書き込み**、配線は未確定
    - tools/link_check.py: 完了条件1〜12の確認と時間の実測、tools/make_gait_reference.py: 照合用の角度列
    - tests: 48件追加（全205件）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
    [gait_reference.csv, robot.yaml]
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2026-09-13 駆動リンクに BODY（胴体姿勢）と TORQUE（脱力）を追加
    とぐろ・鎌首・脱力は展示の見せ場なので、リンク越しでも出せなければ
    行動をリンクに載せられない（Phase 3 の前提）。
    - 0x14 BODY: 胴体ヨー6軸 + 速度 + TTL。**歩容中は NACK(BUSY)**（胴体の持ち主を一つに保つ）
    - 0x15 TORQUE: トルク比。どの停止でも機体側で 100% に戻る
    - device: 未処理の type が BREATH として実行される取りこぼしを塞いだ
    - tests: test_phase2_body.py（8件）。全212件が緑
    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
    [robot.yaml]
2026-09-13 安全の絶対値（構想設計書16章）を設定・実装・テストへ落とした
    出典: ../蛇ロボット_HomeAI_構想設計書.pdf 16章「4重の防御」
    - config: safety_limits（トルク上限 1.2N·m / 最小曲げ半径 40mm / 質量 1.7kg /
    人の近く 8cm/s / 温度 / 通信断）。導出は docs/safety_limits.md
    - **トルク比を「安全上限に対する割合」に変更**。脱力演出の終わりに全力へ戻る経路を塞いだ
    （ratio=1.0 でもストールの 40% = 1.18N·m）。理由は agent/DECISIONS.md
    - セッションが接続先へ必ず上限を書き、書けなければ実機の自律走行を止める（autonomy_blockers）
    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
    [robot.yaml]
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2026-09-15 Stage D: 不変条件をテストで固定し、fault 公開の race を直した
    **flaky ではなく実装の race だった**（60回中3回再現 → 修正後 40回0）。
    `self.fault = ...` と `_publish()` の隙間で `latest()` を読むと、異常を検知したのに
    GUI/監視には「異常なし」が見える瞬間があった。`latest()` が fault と message を
    必ず最新にして隙間を消した。回帰試験を追加。
    - tests/test_phase2_invariants.py（19件）: 起動/ARM/期限/復帰の段差/テレメトリの正直さ/
    壊れた値 を契約として1か所に固定。heartbeat と DRIVE TTL が互いを延長しないことも明示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
2026-09-15 Stage I: MuJoCo 版の歩容掃引（Pareto 候補）と最終の文書更新
    - tools/gait_sweep_mujoco.py: FAST / SMOOTH / LOW_LOAD / SNAKE_LIKE / TIGHT_TURN の
    代表候補と Pareto 非劣解を出す。**単一スコアで1つに決めない**
    - tests/test_gait_sweep_pareto.py: 「速いが重い」と「遅いが軽い」を両方残すことを固定
    - docs / agent/DECISIONS.md: 今回の3つの判断（ARM の boot_id / 可動域の3分割 / C044 のトルク4分割）
    - 全 331 件が緑
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2026-09-17 Bug-1: Stress の飽和を直す（approach gain 0.90→0.12）、駆け込みは別の出来事として扱う
    - 歩いて近づく来場者から逃げない（回帰テスト: 旧 gain で落ちることを確認済み）
    - approach=1.0 を 10 秒与えても stress < 0.95、平衡値 0.77
    - 一次遅れは接近距離を積分するだけで歩行と突進を区別できないため、
    速さが rush_mm_s を超えたら Stress を一段上げる（rush_stress_kick）。RETREAT は駆け込みで発火
    [robot.yaml]
2026-09-17 Bug-2: Energy に活動由来の疲れを追加（冷えている間も気分の休憩が起きる）
    energy = min(温度由来, 1 − fatigue)。gain_move は stop-and-go の稼働率 0.5 を見込んで 0.008
    （レビュー案 0.004 は連続歩行前提で、間欠移動では平衡 0.24 となり休憩が発火しない）
    [robot.yaml]
2026-09-17 Bug-3: 効用ノイズ 0.08→0.15（hysteresis 1.15 を実際に超えるゆらぎにする）
    [robot.yaml]
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2026-09-21 primitives（語彙）/ grammar（文法・config）/ locomotion（移動の段取り）に分離。撫での 3 段応答
    - primitives.py: freeze/twitch/flick/glance_away/tilt/look_at/sag/nuzzle/stretch/hold_breath/eye_flash。状態を知らない
    - grammar.py: behavior.grammar の表（on_notice / on_enter / while）に従って撃つ。未知の語彙は起動時に弾く
    - locomotion.py: 巡回の stop-and-go・2 段階の接近・退避（brain.py を 382 → 278 行に）
    - PETTED: 呼吸を止める（≤200ms）→ 脱力（トルク 40%）→ 追跡中の人の方向へすり寄る（Paro: Sci. Rep. 10:9747）
    - 「もう少し臆病に」を config 1 行で試せる（expression.py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
    [robot.yaml]
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2026-09-21 EXHIBITION profile: 60〜90 秒の体験弧（NOTICE→LOOK→HESITATE/TRACK→APPROACH→ENGAGE→RELAX→LEAVE）と Fear 監査
    固定スクリプトではなく、Utility（OBSERVE 1.3 / APPROACH 1.7、ためらい 0.9）・内部状態（好奇心が calm で育つ）・
    grammar（ENGAGE で sag = RELAX）の係数だけ。3 seeds で 60 秒以内に弧が出る。人に向けた S 字・フル鎌首・速い首振り・
    急加速・直進突撃は使わない（docs/exhibition_profile.md）。CROSSING の来場者に stop_at_x_mm
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2026-09-25 フェーズ 1 レビュー対応: stop は何があっても受理、stop/FAULT で待ち行列破棄と人の操作までロック、stop 前の Task と retain 付き Task を拒否、LWT で OFFLINE、危険物の別枠通知、resolved は人だけ
    - Handler に retained フラグ。LoopbackBroker に will / simulate_disconnect / redeliver
    - 受け側モックは古い safety_state を無効に。tests/test_task_event_api.py（16）。tests/test_mqtt_live.py は Mosquitto があれば実行（無ければ skip）
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2026-09-29 design: reply to ENTRY-0006 (stop <= 52 deg fits knuckle, dome back-plate gives 21 mm cable clearance), scute renders
2026-09-30 design: HEAD INTAKE STUDY 01 (beak intake test piece A x2, head layout, interference report, STLs)
    [A15_ARM_PLA.stl, A15_BASE_PLA.stl, A15_RAMP_TPU.stl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]
2026-09-30 design: gap check of SD-01 (6 poses, 0.5 mm voxels; screening only). Flank V wedges at every bent joint and chin wedge on head pitch-down cannot be removed by shape; ENTRY-D-0003 / OPEN-014. Fixed a 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
2026-09-30 design: KNUCKLE DRUM (full-cylinder knuckle flanks) cuts body-layer gaps ~90%, r ranges per joint/pose, J1 pitch series, head lower-rear fill (172->2 mm3). FLANK SKIRT flap concept tried: did not red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
2026-09-30 design: test piece B2 (step t and clearance c independent), HEAD INTAKE on E3 study, plate-layer options (a) DRUM-FULL / (b) concentric dome caps, J1 pitch window. ~20x residual banner kept for curre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
    [B2_HOOD_PLA.stl, B2_PADS_c0p3_x4_PLA.stl, B2_PADS_c1p0_x4_PLA.stl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]
2026-09-30 design: no floor-touching parts in front of the mouth (15,290 mm3 -> 0), c measured from floor (B2 plate corrected), J1 intake window, lighting recompute with hood. Fusion disconnected: CAD not chang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
    [B2c_FLOOR_PLATE_T0p5_PLA.stl, B2c_FLOOR_PLATE_T1p0_PLA.stl, B2c_FLOOR_PLATE_T1p5_PLA.stl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]
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2026-09-30 Design: Fusion CAD reflection (mouth-front layout, hood-lift, J1 cover+stopper STL), J1 sign correction (CAD + = head down), cover inspection (ENTRY-D-0010)
    [J1_COVER_UPPER_0.stl, J1_STOP_PIN_1.stl, J1_STOP_PIN_3.stl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]
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2026-09-30 Design: consolidated print list (print_all P0-P3), new HT-008/009/010/011 test pieces, ToF board length fix (ENTRY-D-0016)
    [B2_HOOD_PLA.stl, B2_PADS_c0p3_x4_PLA.stl, B2_PADS_c1p0_x4_PLA.stl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]
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
